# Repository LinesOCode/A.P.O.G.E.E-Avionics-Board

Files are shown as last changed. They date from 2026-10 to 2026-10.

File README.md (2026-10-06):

# **A.P.O.G.E.E Avionics**

## Introduction
Hi! Welcome to my project, A.P.O.G.E.E Avionics! I Made this project as a challenge to myself, mainly because I want to soon be able to make a rocket that is entirely my own, design, build, and electronics, and this is a HUGE leap out to that, with the electronics outta the way, I can learn many, many things to come!

A.P.O.G.E.E stands for Avionics, Power, Orientation, Guidance, and Electronics Engine, it represents all of the things I want this project to grow into, and I hope it really does!

## How it works - 
### *Hardware*

This project is mainly based around the Raspberry Pi 2350 Series, i have designed this chip to work with the 2350B/2354B, as they have built in QSPI memory, and without it, you cannot upload the code. For the components, I wont go into extreme depth, but here is the most important things and what they are used for - 

The ***MPU*** - Raspberry Pi 2354B (Main Processing Unit, The Brains of the Avionics Board)

The ***Accelerometer*** - LIS2DH12TR from STMicroelectronics (Sees how fast the rocket changes speed, and uses that to find the speed of the rocket)

The ***Barometer*** - SPL07-003 from Goertek (Finds the hight of the rocket somehow idk man electronics are weird)

The ***Gyroscope*** - A3G4250DTR from STMicroelectronics (Finds the orientation of the rocket, so that we know if we are aiming straight at the ground or up at the sky)

The ***Inertial Mesurement Unit*** - LSM6DS3TR-C from STMicroelectronics (Backup for the Accelerometer and Gyroscope, and also includes a temperature sensor, so I can collect data too!)

The ***Radio Transceiver*** - LoRa2 by Ai Thinker (Dont ask why the company has the word Ai in it, its one of the only ones that work, It is used to send the telemetry data back to my computer)

### *Software*

***Code*** - I coded this project in C++, mainly because of the speed and reliability it has when in a task such as this, and as a fair declaration, I did use AI to code this, as I have no idea on how to use or code those, and it would take a substantial amount of time to learn it, and I WILL add to the code in the future, at least until it is reliable, but as of this being written, I don't have the PCB, nor do i even have funding, so I cant even test the code.

***The Filter*** - For this, I am using an Extended Kalman Filter based code, mainly because of its perks in the aerospace field, and just how good it is a weighting the different data between the components.

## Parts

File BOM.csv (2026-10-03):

Index | LCSC# | MPN | Manufacturer | Package | Customer # | Description | RoHS | Quantity | MOQ | Multiple | Unit Price($) | Extended Price($) | Product Link
1 | C107077 | CC0603KRX7R9BB181 | YAGEO | 603 |  | 180pF ±10% 50V Ceramic Capacitor X7R 0603 | yes | 50 | 50 | 50 | 0.0128 | 0.64 | https://www.lcsc.com/product-detail/C107077.html
2 | C10811 | CNY17F-2 | LITEON | DIP-6 |  | 150mA 300mV@10mA,2.5mA 70V 6V 1.45V DC DIP-6 Transistor, Photovoltaic Output Optoisolators RoHS | yes | 5 | 1 | 1 | 0.0837 | 0.42 | https://www.lcsc.com/product-detail/C10811.html
3 | C51118 | AP2112K-3.3TRG1 | DIODES | SOT-25-5 |  | 3.3V Positive Fixed SOT-25-5 Voltage Regulators - Linear, Low Drop Out (LDO) Regulators RoHS | yes | 5 | 5 | 5 | 0 | 0 | https://www.lcsc.com/product-detail/C51118.html
4 | C15850 | CL21A106KAYNNNE | Samsung Electro-Mechanics | 805 |  | 10uF ±10% 25V Ceramic Capacitor X5R 0805 | yes | 20 | 20 | 20 | 0 | 0 | https://www.lcsc.com/product-detail/C15850.html
5 | C4944014 | 12M 16PF 50PPM | SOSET | HC-49S-SMD-2P-Mini |  | Crystal 12MHz ±50ppm 16pF HC-49S-SMD-2P-Mini | yes | 10 | 10 | 10 | 0.0382 | 0.38 | https://www.lcsc.com/product-detail/C4944014.html
6 | C561716 | FN03N270J500PLG | PSA | 201 |  | 27pF ±5% 50V Ceramic Capacitor C0G 0201 | yes | 100 | 100 | 100 | 0.0012 | 0.12 | https://www.lcsc.com/product-detail/C561716.html
7 | C21190 | 0603WAF1001T5E | UNI-ROYAL | 603 |  | 1kΩ ±1% 100mW 0603 Thick Film Resistor | yes | 100 | 100 | 100 | 0.0033 | 0.33 | https://www.lcsc.com/product-detail/C21190.html
8 | C14663 | CC0603KRX7R9BB104 | YAGEO | 603 |  | 100nF ±10% 50V Ceramic Capacitor X7R 0603 | yes | 50 | 50 | 50 | 0 | 0 | https://www.lcsc.com/product-detail/C14663.html
9 | C25804 | 0603WAF1002T5E | UNI-ROYAL | 603 |  | 10kΩ ±1% 100mW 0603 Thick Film Resistor | yes | 100 | 100 | 100 | 0.004 | 0.4 | https://www.lcsc.com/product-detail/C25804.html
10 | C90039 | Ra-02 | Ai-Thinker | SMD-16P |  | IPEX interface -141dBm SPI SMD-16P RF Transceiver Modules and Modems RoHS | yes | 5 | 1 | 1 | 7.4885 | 37.44 | https://www.lcsc.com/product-detail/C90039.html
11 | C5356059 | CON-SMA-EDGE-S | RF Solutions | SMD |  | SMD Coaxial Connector (RF) Assemblies RoHS | yes | 2 | 1 | 1 | 4.2063 | 8.41 | https://www.lcsc.com/product-detail/C5356059.html
12 | C20917 | AO3400A | AOS | SOT-23 |  | N-Channel 30V Surface Mount SOT-23-3L | yes | 25 | 5 | 5 | 0.0853 | 2.13 | https://www.lcsc.com/product-detail/C20917.html
13 | C2933369 | FRC0805F2200TS | FOJAN | 805 |  | 220Ω ±1% 125mW 0805 Thick Film Resistor | yes | 100 | 100 | 100 | 0.004 | 0.4 | https://www.lcsc.com/product-detail/C2933369.html
14 | C2909831 | 1N4007 | YONGYUTAI | SMA |  | Diode Independent 1kV 1A Surface Mount SMA | yes | 50 | 50 | 50 | 0.0087 | 0.44 | https://www.lcsc.com/product-detail/C2909831.html
15 | C3253727 | SPL07-003 | Goertek | SMD-10P |  | 30Kpa~1.1bar SMD-10P Pressure Sensors, Transducers RoHS | yes | 6 | 1 | 1 | 0.8817 | 5.29 | https://www.lcsc.com/product-detail/C3253727.html
16 | C967633 | LSM6DS3TR-C | ST | LGA-14(2.5x3) |  | LGA-14(2.5x3) IMUs (Inertial Measurement Units) RoHS | yes | 6 | 1 | 1 | 1.5274 | 9.16 | https://www.lcsc.com/product-detail/C967633.html
17 | C110926 | LIS2DH12TR | ST | LGA-12(2x2) |  | LGA-12(2x2) Accelerometers RoHS | yes | 6 | 1 | 1 | 0.9328 | 5.6 | https://www.lcsc.com/product-detail/C110926.html
18 | C2655092 | A3G4250DTR | ST | TFLGA-16 |  | TFLGA-16 Gyroscopes RoHS | yes | 6 | 1 | 1 | 1.8523 | 11.11 | https://www.lcsc.com/product-detail/C2655092.html
19 | C165948 | TYPE-C-31-M-12 | Korean Hroparts Elec | SMD |  | USB-C (USB TYPE-C) Receptacle Connector 16 Position Surface Mount | yes | 10 | 5 | 5 | 0.1724 | 1.72 | https://www.lcsc.com/product-detail/C165948.html
20 | C55098610 | HRC0805F5101FNTN | HWA CHN | 805 |  | 125mW 5.1kΩ 150V Thick Film Resistor ±1% ±100ppm/℃ 0805 Chip Resistor - Surface Mount | yes | 100 | 100 | 100 | 0.0012 | 0.12 | https://www.lcsc.com/product-detail/C55098610.html
21 | C318884 | TS-1187A-B-A-B | XKB Connection | SMD-4P,5.1x5.1mm |  | Tactile Switch SPST 160gf 1.5mm 5.1mm x 5.1mm Surface Mount | yes | 20 | 20 | 20 | 0.0207 | 0.41 | https://www.lcsc.com/product-detail/C318884.html
22 | C2286 | KT-0603R | Hubei KENTO Elec | 603 |  | Red 645nm LED Indication - Discrete 2.4V 0603 | yes | 100 | 100 | 100 | 0.0075 | 0.75 | https://www.lcsc.com/product-detail/C2286.html
23 | C2287 | KT-0603Y | Hubei KENTO Elec | 603 |  | Yellow 596nm LED Indication - Discrete 2.4V 0603 | yes | 50 | 50 | 50 | 0.0108 | 0.54 | https://www.lcsc.com/product-detail/C2287.html
24 | C2297 | KT-0805G | Hubei KENTO Elec | 805 |  | Emerald Green 525nm LED Indication - Discrete 2.6V~3.1V 0805 | yes | 50 | 50 | 50 | 0.0165 | 0.83 | https://www.lcsc.com/product-detail/C2297.html
25 | C2933198 | FRC0603F3300TS | FOJAN | 603 |  | 330Ω ±1% 100mW 0603 Thick Film Resistor | yes | 100 | 100 | 100 | 0.0027 | 0.27 | https://www.lcsc.com/product-detail/C2933198.html
26 | C55014110 | SMD-0955-05-27 | S&S | SMD,9x9mm |  | Active Buzzer (Built-in Driving Circuit) 2.7kHz 5V Electromagnetic SMD,9x9mm Alarms, Buzzers, and Sirens RoHS | yes | 6 | 1 | 1 | 0.1983 | 1.19 | https://www.lcsc.com/product-detail/C55014110.html
27 | C39843328 | RP2354B | Raspberry Pi | QFN-80-EP(10x10) |  | ARM Cortex-M33 32 Bit 150MHz QFN-80-EP(10x10) Microcontrollers | yes | 6 | 1 | 1 | 1.5799 | 9.48 | https://www.lcsc.com/product-detail/C39843328.html
28 | C41367225 | BSMD1206C-1300T | BHFUSE | 1206 |  | 3A 72V Fuse Surface Mount 1206 | yes | 30 | 10 | 10 | 0.0575 | 1.73 | https://www.lcsc.com/product-detail/C41367225.html
29 | C176959 | AP2210K-3.3TRG1 | DIODES | SOT-23-5 |  | 3.3V Positive Fixed SOT-23-5 Voltage Regulators - Linear, Low Drop Out (LDO) Regulators RoHS | yes | 5 | 5 | 5 | 0.1912 | 0.96 | https://www.lcsc.com/product-detail/C176959.html
30 | C2907002 | FRC0603F1001TS | FOJAN | 603 |  | 1kΩ ±1% 100mW 0603 Thick Film Resistor | yes | 100 | 100 | 100 | 0.0028 | 0.28 | https://www.lcsc.com/product-detail/C2907002.html
31 | C23848 | MBR0520LT1G | onsemi | SOD-123 |  | Diode 20V 500mA Surface Mount SOD-123 | yes | 50 | 5 | 5 | 0.084 | 4.2 | https://www.lcsc.com/product-detail/C23848.html
32 | C29266 | CL05A105KO5NNNC | Samsung Electro-Mechanics | 402 |  | 1uF ±10% 16V Ceramic Capacitor X5R 0402 | yes | 50 | 50 | 50 | 0.0082 | 0.41 | https://www.lcsc.com/product-detail/C29266.html
33 | C49441431 | JBL-102010052 | JBL | SMD |  | -40℃~+85℃ Push-Push 1.8mm Connector and Ejector MicroSD Card (TF Card) SMD PC Card Sockets RoHS | yes | 5 | 5 | 5 | 0.0874 | 0.44 | https://www.lcsc.com/product-detail/C49441431.html
34 | C500019 | DB127V-5.0-2P-BU-S | DORABO | Through Hole,P=5mm |  | 2 Position Wire to Board Terminal Block Through Hole 5mm | yes | 50 | 5 | 5 | 0.1264 | 6.32 | https://www.lcsc.com/product-detail/C500019.html
Total Components Cost - $127 | Tax and Shipping included in price shown
PCB Cost - $160 | Tax and Shipping included in price shown
Manufaturing Tools Cost - $123 | Tax and Shipping included in price shown
 | Soldering Iron and Heat Gun Station - $60
 | Solder Paste - $15
 | Flux - $15
 | Helping Hands - $25
Total Cost - $410

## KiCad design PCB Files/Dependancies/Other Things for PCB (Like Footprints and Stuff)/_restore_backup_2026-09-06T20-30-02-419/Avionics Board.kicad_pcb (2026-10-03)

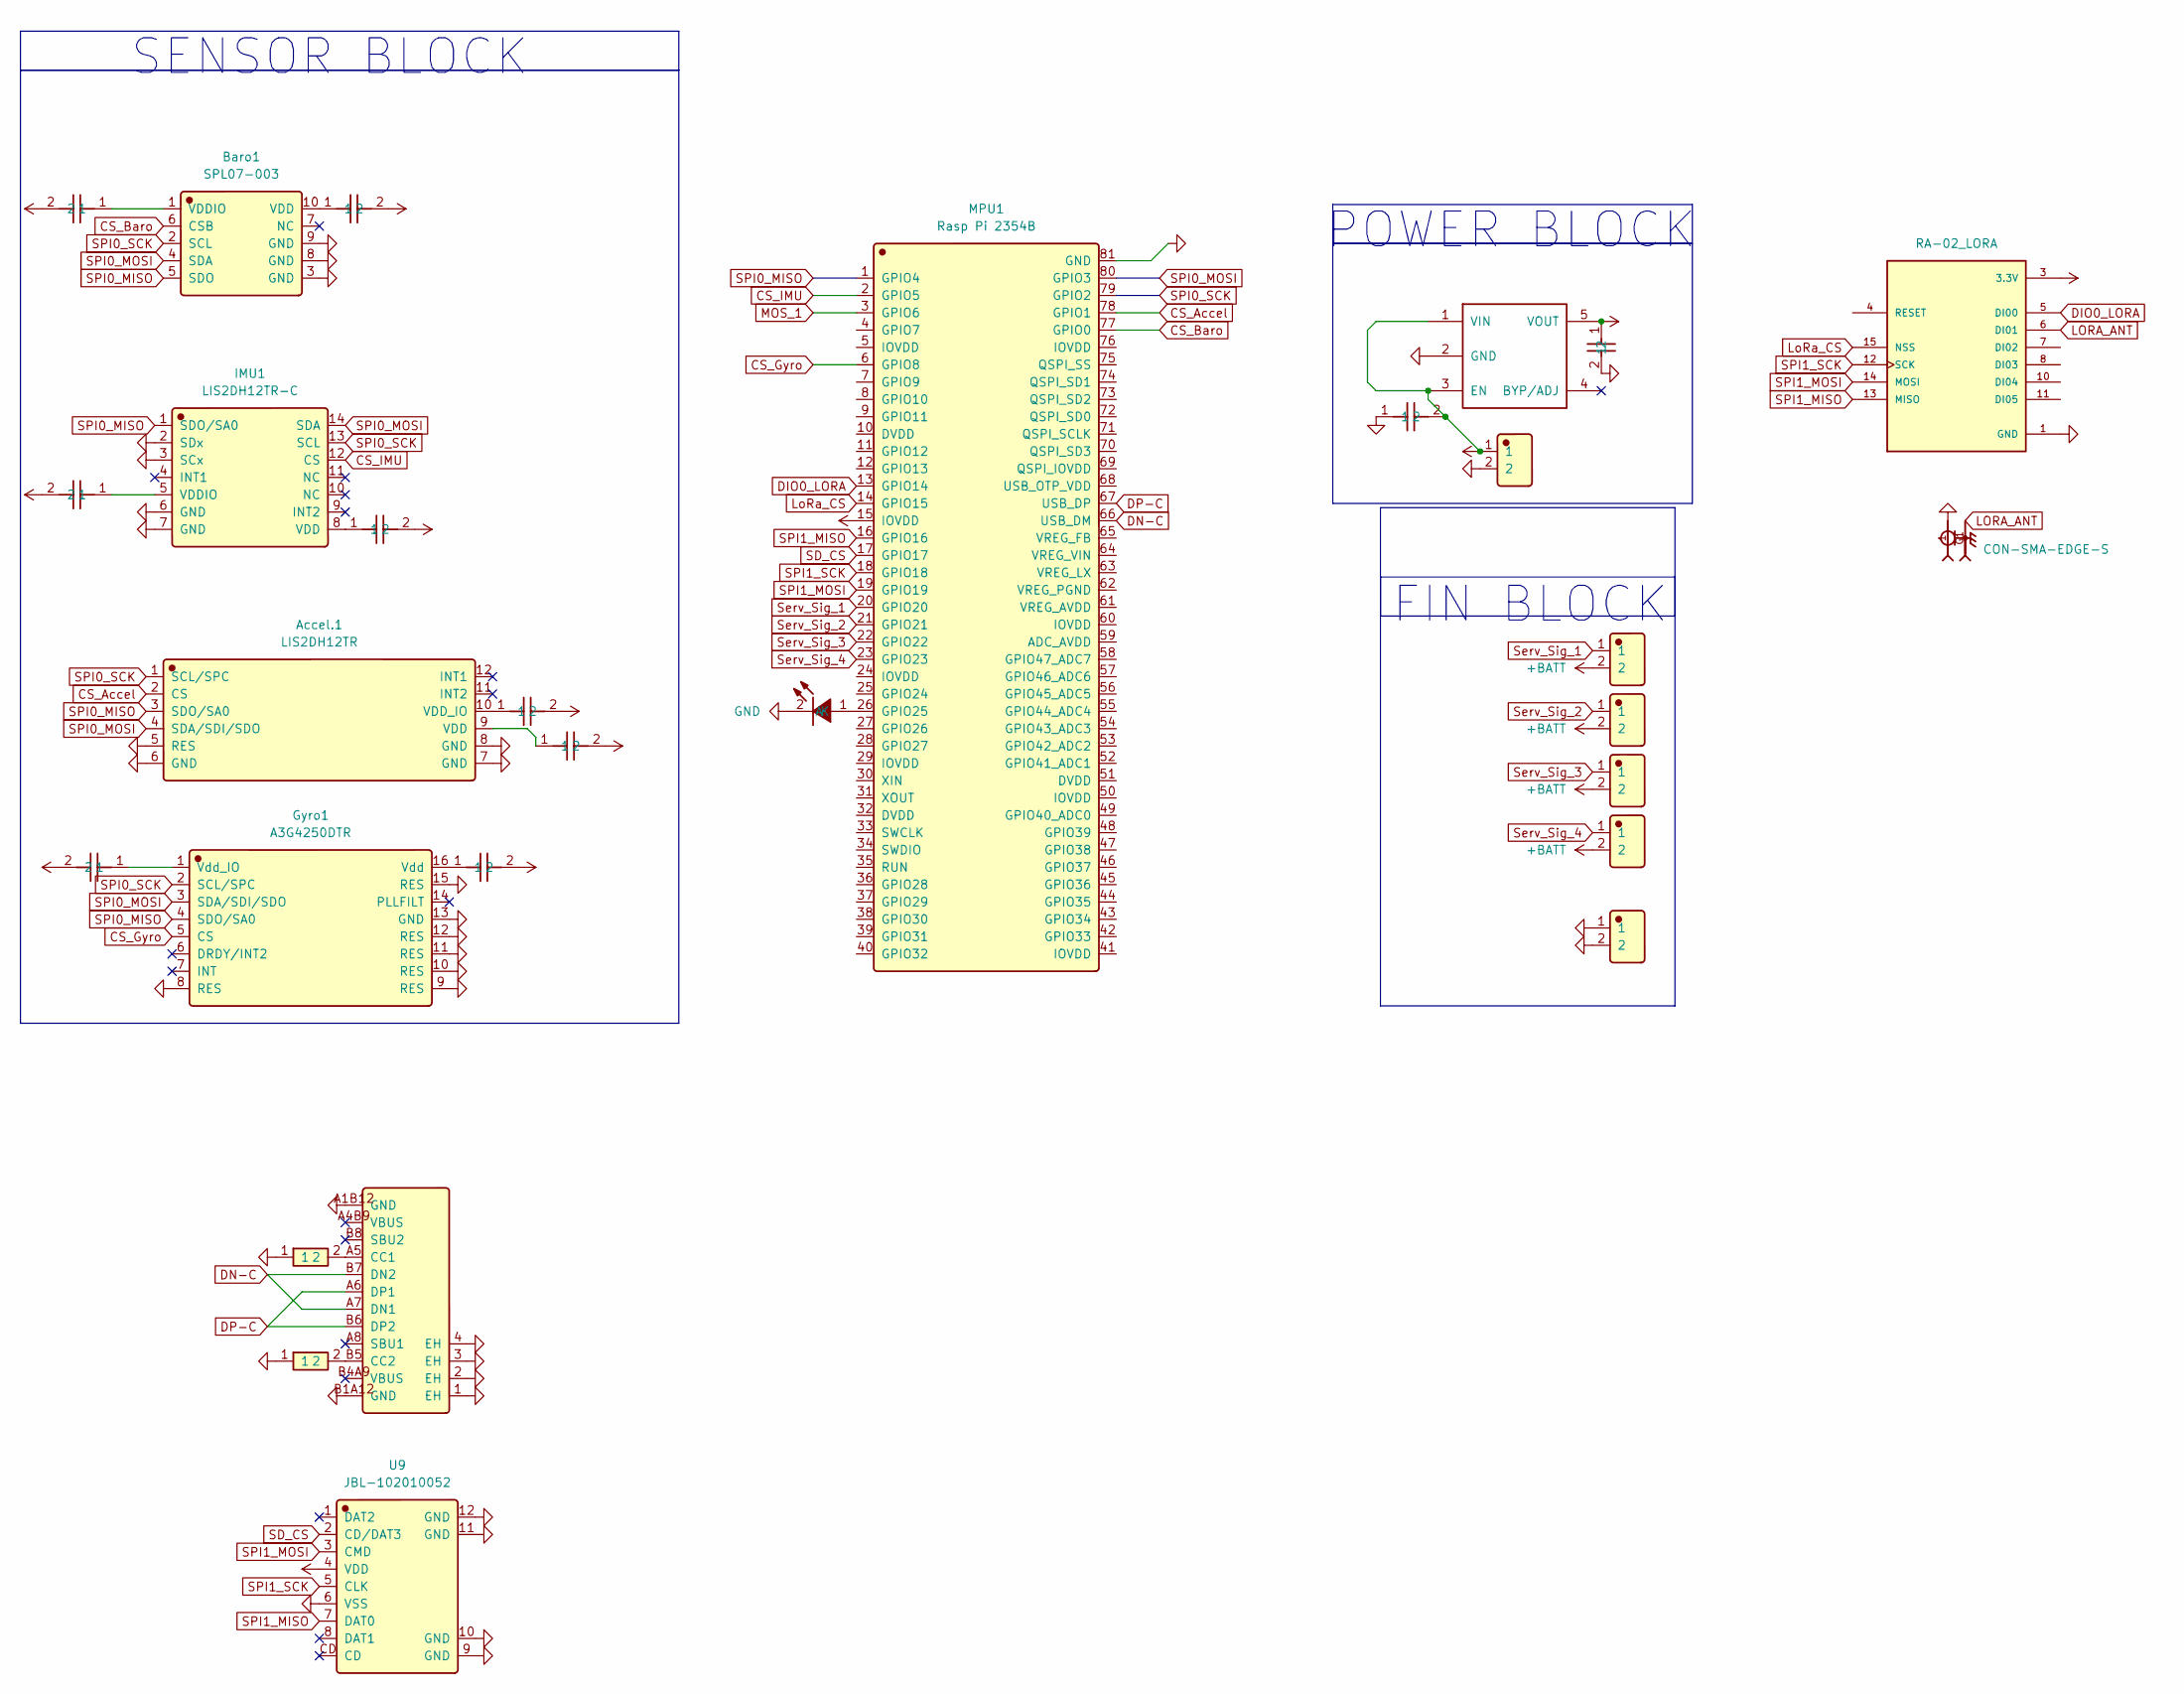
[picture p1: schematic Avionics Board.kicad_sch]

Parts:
Accel.1: LIS2DH12TR; LGA-12_2x2mm_P0.5mm; Manufacturer Part LIS2DH12TR; LCSC C110926
Baro1: SPL07-003; Manufacturer Part SPL07-003; LCSC C3253727
C1, C2, C3, C4, C5, C6, C7, C8: .1 uF; C_0603_1608Metric; Manufacturer Part CC0603KRX7R9BB104; LCSC C14663
C9: CL21A106KAYNNNE; C_0805_2012Metric; Manufacturer Part CL21A106KAYNNNE; LCSC C15850
C10: CL05A105KO5NNNC; C_0402_1005Metric; Manufacturer Part CL05A105KO5NNNC; LCSC C29266
Gyro1: A3G4250DTR; QFN-16-1EP_4x4mm_P0.65mm_EP2.1x2.1mm; Manufacturer Part A3G4250DTR; LCSC C2655092
IMU1: LIS2DH12TR-C; Bosch_LGA-14_3x2.5mm_P0.5mm; Manufacturer Part LSM6DS3TR-C; LCSC C967633
J1: CON-SMA-EDGE-S; RFSOLUTIONS_CON-SMA-EDGE-S; PARTREV 1
LED1: 0805G_Green; Manufacturer Part KT-0805G; LCSC C2297
MPU1: Rasp Pi 2354B; QFN-80-1EP_10x10mm_P0.4mm_EP3.4x3.4mm; Manufacturer Part RP2354B; LCSC C39843328
R1, R2: HRC0805F5101FNTN; R_0805_2012Metric; Manufacturer Part HRC0805F5101FNTN; LCSC C55098610
U2: Volt_Reg; SOT-23-5; Manufacturer Part AP2210K-3.3TRG1; LCSC C176959
U3, U4, U5, U6, U7, U11: DB127V-5_0-2P-BU-S; Manufacturer Part DB127V-5.0-2P-BU-S; LCSC C500019
U9: JBL-102010052; Micro_SD_-_Avionics; Manufacturer Part JBL-102010052; LCSC C49441431
U10: RA-02_LORA; MODULE_RA-02_LORA; PARTREV 2018/03/02
USBC1: TYPE-C-31-M-12; USB_C_Receptacle_HRO_TYPE-C-31-M-12; Manufacturer Part TYPE-C-31-M-12; LCSC C165948

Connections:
+3.3V: C1.2, C2.2, C3.2, C4.2, C5.2, C6.2, C7.2, C8.2, C10.1, MPU1.15 (IOVDD), U2.5 (VOUT), U9.4 (VDD), U10.3 (3.3V)
+BATT: C9.2, U2.1 (VIN), U2.3 (EN), U3.2, U4.2, U5.2, U6.2, U11.1
CS_Accel: Accel.1.2 (CS), MPU1.78 (GPIO1)
CS_Baro: Baro1.6 (CSB), MPU1.77 (GPIO0)
CS_Gyro: Gyro1.5 (CS), MPU1.6 (GPIO8)
CS_IMU: IMU1.12 (CS), MPU1.2 (GPIO5)
DIO0_LORA: MPU1.13 (GPIO14), U10.5 (DI00)
DN-C: MPU1.66 (USB_DM), USBC1.A7 (DN1), USBC1.B7 (DN2)
DP-C: MPU1.67 (USB_DP), USBC1.A6 (DP1), USBC1.B6 (DP2)
GND: Accel.1.5 (RES), Accel.1.6 (GND), Accel.1.7 (GND), Accel.1.8 (GND), Baro1.3 (GND), Baro1.8 (GND), Baro1.9 (GND), C9.1, C10.2, Gyro1.8 (RES), Gyro1.9 (RES), Gyro1.10 (RES), Gyro1.11 (RES), Gyro1.12 (RES), Gyro1.13 (GND), Gyro1.15 (RES), IMU1.2 (SDx), IMU1.3 (SCx), IMU1.6 (GND), IMU1.7 (GND), J1.1, LED1.2 (K), MPU1.81 (GND), R1.1, R2.1, U2.2 (GND), U7.1, U7.2, U9.6 (VSS), U9.9 (GND), U9.10 (GND), U9.11 (GND), U9.12 (GND), U10.1 (GND), U10.2 (GND), U10.9 (GND), U10.16 (GND), U11.2, USBC1.1 (EH), USBC1.2 (EH), USBC1.3 (EH), USBC1.4 (EH), USBC1.A1B12 (GND), USBC1.B1A12 (GND)
LoRa_CS: MPU1.14 (GPIO15), U10.15 (NSS)
MOS_1: MPU1.3 (GPIO6)
unnamed: Accel.1.9 (VDD), C1.1
unnamed: Accel.1.10 (VDD_IO), C2.1
unnamed: Baro1.10 (VDD), C7.1
unnamed: Baro1.1 (VDDIO), C8.1
unnamed: C5.1, Gyro1.16 (Vdd)
unnamed: C6.1, Gyro1.1 (Vdd_IO)
unnamed: C3.1, IMU1.8 (VDD)
unnamed: C4.1, IMU1.5 (VDDIO)
unnamed: J1.G1, J1.G2, J1.G3, J1.G4, U10.6 (DI01)
unnamed: LED1.1 (A), MPU1.26 (GPIO25)
unnamed: R2.2, USBC1.A5 (CC1)
unnamed: R1.2, USBC1.B5 (CC2)
SD_CS: MPU1.17 (GPIO17), U9.2 (CD/DAT3)
SPI0_MISO: Accel.1.3 (SDO/SA0), Baro1.5 (SDO), Gyro1.4 (SDO/SA0), IMU1.1 (SDO/SA0), MPU1.1 (GPIO4)
SPI0_MOSI: Accel.1.4 (SDA/SDI/SDO), Baro1.4 (SDA), Gyro1.3 (SDA/SDI/SDO), IMU1.14 (SDA), MPU1.80 (GPIO3)
SPI0_SCK: Accel.1.1 (SCL/SPC), Baro1.2 (SCL), Gyro1.2 (SCL/SPC), IMU1.13 (SCL), MPU1.79 (GPIO2)
SPI1_MISO: MPU1.16 (GPIO16), U9.7 (DAT0), U10.13 (MISO)
SPI1_MOSI: MPU1.19 (GPIO19), U9.3 (CMD), U10.14 (MOSI)
SPI1_SCK: MPU1.18 (GPIO18), U9.5 (CLK), U10.12 (SCK)
Serv_Sig_1: MPU1.20 (GPIO20), U3.1
Serv_Sig_2: MPU1.21 (GPIO21), U4.1
Serv_Sig_3: MPU1.22 (GPIO22), U5.1
Serv_Sig_4: MPU1.23 (GPIO23), U6.1

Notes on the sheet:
FIN BLOCK
POWER BLOCK
SENSOR BLOCK

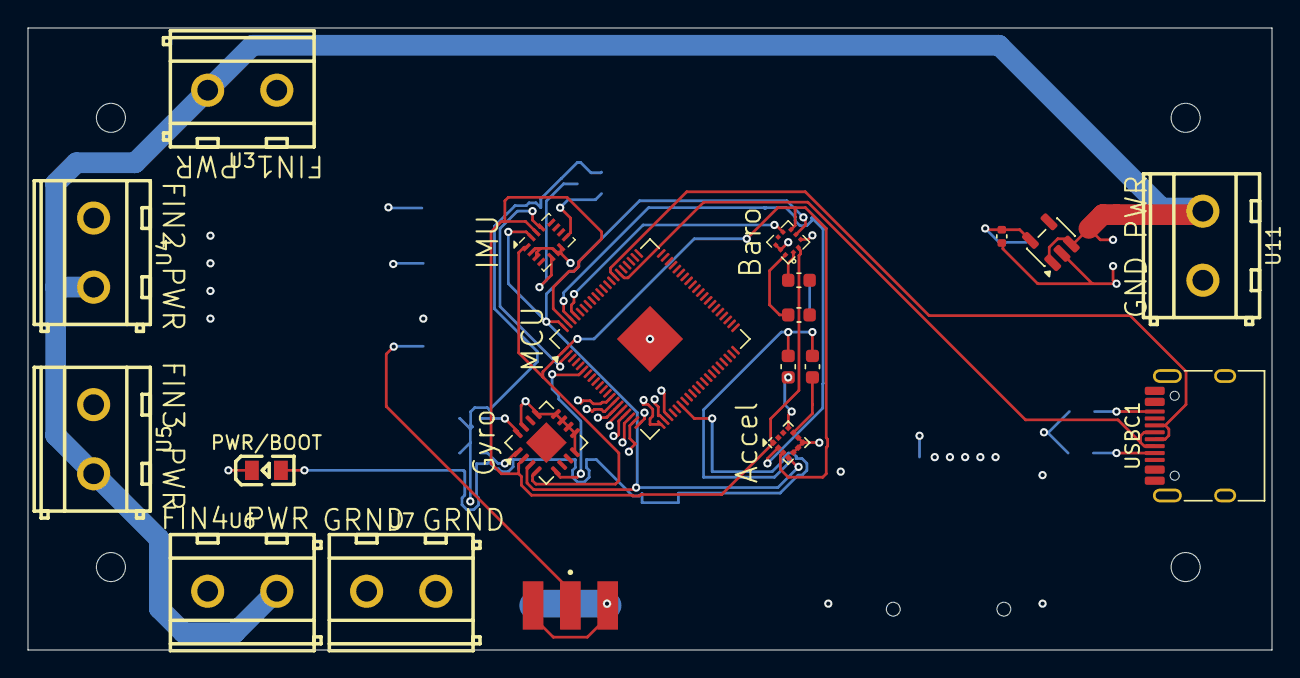
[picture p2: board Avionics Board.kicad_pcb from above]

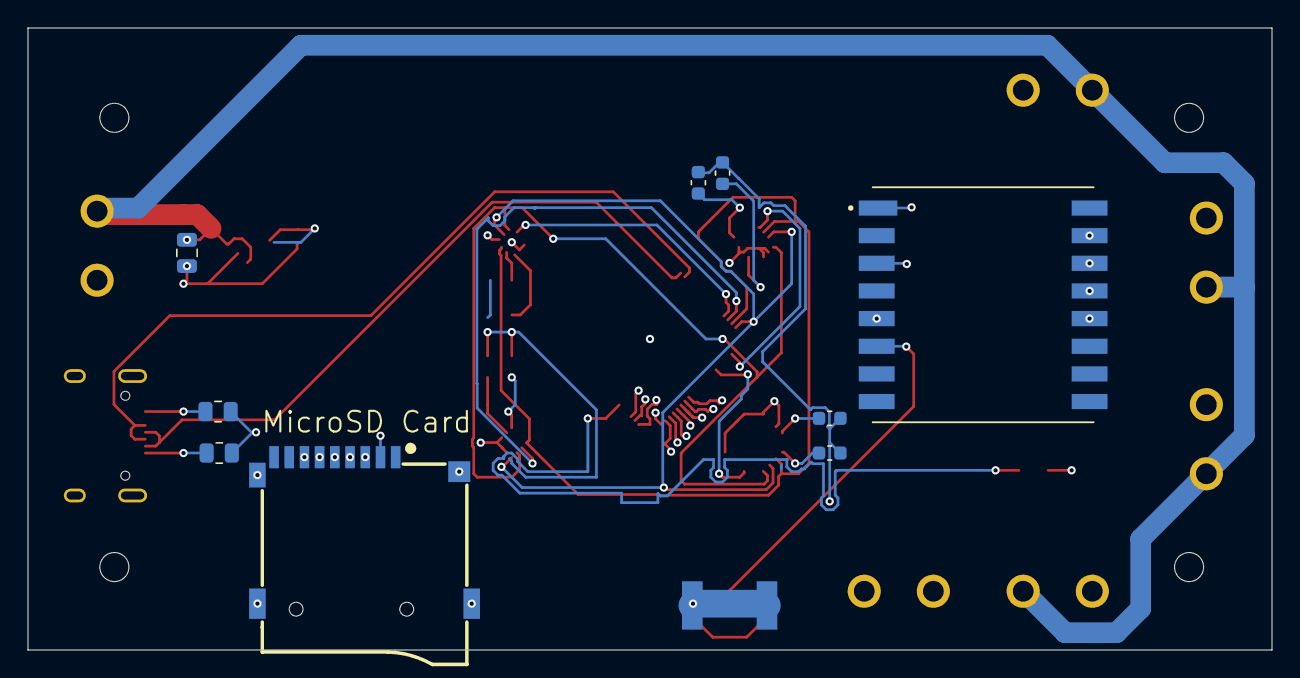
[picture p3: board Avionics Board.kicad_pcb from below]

Board: 4 copper layers, 90.0 x 45.0 mm, 27 parts (8 on the bottom side), 31 nets.

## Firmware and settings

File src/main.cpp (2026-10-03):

#include <Arduino.h>
#include <SPI.h>
#include <Servo.h>
#include <RadioLib.h>
#include <SD.h>
#include <math.h>
#include <string.h>
#include <stdio.h>

<<<<<<< HEAD

// ========================== Deadlock Safety ================================

spin_lock_t *telemetryLock;   // Remains purely for the Core0 -> Core1 FIFO snapshot packet
spin_lock_t *sensorBusLock;   // ONLY if multiple tasks on Core 0 need to share sensorSPI
spin_lock_t *storageBusLock;  // ONLY if multiple tasks on Core 1 need to share the standard SPI


=======
// Minimal watchdog stubs for single-core ARM builds (no Pico watchdog)
static inline void watchdog_update() {}
static inline void watchdog_enable(uint32_t ms, bool pause_on_debug) {}
>>>>>>> e234959169edb00d9b9b414ebf627fc5142cae8a

// ========================== PIN ASSIGNMENTS ================================
// All four sensors share this SPI bus. Only one CS line may be low at a time.
// Keep board wiring changes in this block.
// Sensor bus: configurable SPI pins (change these variables if you re-wire)
// Default mapping provided by user (GPIO numbers):
// SCK = GPIO2, MOSI = GPIO3, MISO = GPIO4
const uint8_t SENSOR_SPI_SCK_PIN = 2;
const uint8_t SENSOR_SPI_MOSI_PIN = 3;
const uint8_t SENSOR_SPI_MISO_PIN = 4;
// Storage/radio bus: Arduino global SPI0 pins, separate from all sensors.
const uint8_t STORAGE_SPI_SCK_PIN = 18;
const uint8_t STORAGE_SPI_MOSI_PIN = 19;
const uint8_t STORAGE_SPI_MISO_PIN = 16;
// Sensor chip-selects (changeable variables)
// Provided mapping from user:
// IMU CS GPIO5, Gyro CS GPIO8, Baro CS GPIO0, Accel CS GPIO1
const uint8_t IMU_SENSOR_CS = 5;   // ST LSM6DS3TR accelerometer + gyro
const uint8_t GYRO_SENSOR_CS = 8;  // ST A3G4250DTR gyro
const uint8_t BARO_SENSOR_CS = 0;  // Goertek SPL07-003 barometer
const uint8_t ACCEL_SENSOR_CS = 1; // ST LIS2DH12TR accelerometer
const uint8_t MOSFET_ARM_INPUT_PIN = 12;
const uint8_t DROGUE_PARACHUTE_GATE_PIN = 26;
const uint8_t MAIN_PARACHUTE_GATE_PIN = 9;
const uint8_t FIN_1_POWER_GATE_PIN = 13;
const uint8_t FIN_2_POWER_GATE_PIN = 14;
const uint8_t FIN_3_POWER_GATE_PIN = 15;
const uint8_t FIN_4_POWER_GATE_PIN = 20;
const uint8_t FIN_1_SERVO_SIGNAL_PIN = 21;
const uint8_t FIN_2_SERVO_SIGNAL_PIN = 22;
const uint8_t FIN_3_SERVO_SIGNAL_PIN = 23;
const uint8_t FIN_4_SERVO_SIGNAL_PIN = 24;
const uint8_t MISC_MOSFET_GATE_PIN = 25;
const uint8_t SD_CARD_CS_PIN = 27;       // MicroSD card chip select, storage SPI0
const uint8_t LORA_RADIO_CS_PIN = 28;    // HopeRF RFM95W-915S2 NSS, storage SPI0
const uint8_t LORA_RADIO_RESET_PIN = 1;
const uint8_t LORA_RADIO_DIO0_PIN = 0;
const uint8_t W25Q16_FLASH_CS_PIN = 3;   // Winbond W25Q16JVSSIQ, 16 Mbit
const float high_altitude_threshold_m = 1000.0f;
const float high_altitude_reset_m = 950.0f;
const uint8_t high_altitude_confirmations = 8;
const uint32_t sensor_health_period_ms = 250;
const uint8_t sensor_recovery_limit = 3;
const float max_fin_correction_deg = 12.0f;
const float maximum_control_angle_deg = 45.0f;
const bool FIN_CONTROL_ENABLED = false; // Explicitly enable only after restrained bench testing.
const float ATTITUDE_ACCEL_CORRECTION = 0.02f;
const uint32_t BAROMETER_SAMPLE_PERIOD_MS = 62;
const uint32_t TELEMETRY_PERIOD_MS = 50;
const uint32_t SD_FLUSH_PERIOD_MS = 1000;
const uint8_t INTER_RP_PACKET_MAGIC = 0xa7;

// Use a dedicated SPI instance for sensors so pins can be remapped at runtime
SPIClass sensorSPI;
SPISettings sensor_spi(8000000, MSBFIRST, SPI_MODE0);
SPISettings storage_spi(25000000, MSBFIRST, SPI_MODE0);
File flightLog;
SX1276 loraRadio = new Module(LORA_RADIO_CS_PIN, LORA_RADIO_DIO0_PIN, LORA_RADIO_RESET_PIN,
                              RADIOLIB_NC, SPI, SPISettings(8000000, MSBFIRST, SPI_MODE0));
bool sdCardReady = false;
bool loraReady = false;
bool flashReady = false;
uint32_t flashJedecId = 0;
uint32_t lastSdFlushMs = 0;
uint16_t interRpSequence = 0;
// single-core build: no spinlocks or multicore usage

struct FlightStatePacket {
  uint8_t magic;
  uint8_t version;
  uint16_t sequence;
  uint32_t timestampMs;
  float altitudeM;
  float velocityMps;
  float rollRad;
  float pitchRad;
  float pressurePa;
  uint8_t sensorHealthMask;
  uint8_t checksum;
};

static void publishRemoteTelemetry(const FlightStatePacket &packet);

static uint8_t packetChecksum(const FlightStatePacket &packet) {
  const uint8_t *bytes = reinterpret_cast<const uint8_t *>(&packet);
  uint8_t checksum = 0;
  for (size_t index = 0; index < sizeof(packet) - 1; ++index) checksum ^= bytes[index];
  return checksum;
}

static uint32_t readW25q16JedecId() {
  uint8_t id[3];
  SPI.beginTransaction(storage_spi);
  digitalWrite(W25Q16_FLASH_CS_PIN, LOW);
  SPI.transfer(0x9f);
  id[0] = SPI.transfer(0);
  id[1] = SPI.transfer(0);
  id[2] = SPI.transfer(0);
  digitalWrite(W25Q16_FLASH_CS_PIN, HIGH);
  SPI.endTransaction();
  return (static_cast<uint32_t>(id[0]) << 16) |
         (static_cast<uint32_t>(id[1]) << 8) | id[2];
}

static void initializeExternalMemory() {
  pinMode(W25Q16_FLASH_CS_PIN, OUTPUT);
  digitalWrite(W25Q16_FLASH_CS_PIN, HIGH);
  flashJedecId = readW25q16JedecId();
  flashReady = flashJedecId == 0xef4015UL;
  if (flashReady) {
    Serial.println("W25Q16 detected on core 0: external 16 Mbit SPI/QSPI flash");
  } else {
    Serial.println("W25Q16 not detected; onboard flash is unchanged");
  }
}

static uint8_t spiRead8(uint8_t chipSelect, uint8_t reg) {
  sensorSPI.beginTransaction(sensor_spi);
  digitalWrite(chipSelect, LOW);
  sensorSPI.transfer(reg | 0x80);
  uint8_t value = sensorSPI.transfer(0);
  digitalWrite(chipSelect, HIGH);
  sensorSPI.endTransaction();
  return value;
}

static void spiWrite8(uint8_t chipSelect, uint8_t reg, uint8_t value) {
  sensorSPI.beginTransaction(sensor_spi);
  digitalWrite(chipSelect, LOW);
  sensorSPI.transfer(reg & 0x7f);
  sensorSPI.transfer(value);
  digitalWrite(chipSelect, HIGH);
  sensorSPI.endTransaction();
}

static void spiRead(uint8_t chipSelect, uint8_t reg, uint8_t *buffer, size_t length) {
  sensorSPI.beginTransaction(sensor_spi);
  digitalWrite(chipSelect, LOW);
  sensorSPI.transfer(reg | 0x80 | (length > 1 ? 0x40 : 0));
  memset(buffer, 0, length);
  sensorSPI.transfer(buffer, length);
  digitalWrite(chipSelect, HIGH);
  sensorSPI.endTransaction();
}

enum SensorId : uint8_t { SENSOR_SPL07, SENSOR_LSM6, SENSOR_LIS2DH, SENSOR_A3G4250 };
uint8_t sensorFailures[4] = {0, 0, 0, 0};
bool sensorHealthy[4] = {false, false, false, false};
uint32_t lastSensorHealthCheck = 0;

class Spl07 {
 public:
  explicit Spl07(uint8_t chipSelect) : chipSelect_(chipSelect) {}

  bool begin() {
    if (spiRead8(chipSelect_, 0x0d) != 0x10) return false;
    uint8_t calibration[18];
    spiRead(chipSelect_, 0x10, calibration, sizeof(calibration));
    c0_ = signExtend((calibration[0] << 4) | (calibration[1] >> 4), 12);
    c1_ = signExtend(((calibration[1] & 0x0f) << 8) | calibration[2], 12);
    c00_ = signExtend((calibration[3] << 12) | (calibration[4] << 4) | (calibration[5] >> 4), 20);
    c10_ = signExtend(((calibration[5] & 0x0f) << 16) | (calibration[6] << 8) | calibration[7], 20);
    c01_ = signExtend((calibration[8] << 8) | calibration[9], 16);
    c11_ = signExtend((calibration[10] << 8) | calibration[11], 16);
    c20_ = signExtend((calibration[12] << 8) | calibration[13], 16);
    c21_ = signExtend((calibration[14] << 8) | calibration[15], 16);
    c30_ = signExtend((calibration[16] << 8) | calibration[17], 16);
    // 16 measurements/s, 8x oversampling for both pressure and temperature.
    spiWrite8(chipSelect_, 0x06, 0x24);
    spiWrite8(chipSelect_, 0x07, 0xa7);
    spiWrite8(chipSelect_, 0x08, 0x07);
    spiWrite8(chipSelect_, 0x09, 0x00);
    return true;
  }

  float pressurePa() {
    uint8_t data[6];
    spiRead(chipSelect_, 0x00, data, sizeof(data));
    int32_t pressure = signExtend((data[0] << 16) | (data[1] << 8) | data[2], 24);
    int32_t temperature = signExtend((data[3] << 16) | (data[4] << 8) | data[5], 24);
    float pressureScale = 7864320.0f; // 8x oversampling scale factor
    float temperatureScale = 7864320.0f;
    float pressureScaled = pressure / pressureScale;
    float temperatureScaled = temperature / temperatureScale;
    float pressureCompensated = c00_ + pressureScaled * (c10_ + pressureScaled * (c20_ + pressureScaled * c30_));
    pressureCompensated += temperatureScaled * c01_ + pressureScaled * temperatureScaled * (c11_ + pressureScaled * c21_);
    return pressureCompensated * 100.0f;
  }

 private:
  static int32_t signExtend(uint32_t value, uint8_t bits) {
    uint32_t sign = 1UL << (bits - 1);
    return (value ^ sign) - sign;
  }
  uint8_t chipSelect_;
  int32_t c0_ = 0, c1_ = 0, c00_ = 0, c10_ = 0;
  int32_t c01_ = 0, c11_ = 0, c20_ = 0, c21_ = 0, c30_ = 0;
};

struct Vector3 { float x; float y; float z; };
struct ImuSample { Vector3 acceleration; Vector3 gyro; };

static ImuSample readLsm6(uint8_t chipSelect) {
  uint8_t data[12];
  spiRead(chipSelect, 0x22, data, sizeof(data));
  const float gyroScale = 8.75e-3f * DEG_TO_RAD;
  const float accelScale = 0.061f * 9.80665e-3f;
  ImuSample sample;
  sample.acceleration = {((int16_t)(data[6] | data[7] << 8)) * accelScale,
                         ((int16_t)(data[8] | data[9] << 8)) * accelScale,
                         ((int16_t)(data[10] | data[11] << 8)) * accelScale};
  sample.gyro = {((int16_t)(data[0] | data[1] << 8)) * gyroScale,
                 ((int16_t)(data[2] | data[3] << 8)) * gyroScale,
                 ((int16_t)(data[4] | data[5] << 8)) * gyroScale};
  return sample;
}

static Vector3 readLis2dh(uint8_t chipSelect) {
  uint8_t data[6];
  spiRead(chipSelect, 0x28, data, sizeof(data));
  const float scale = 0.001f * 9.80665f; // +/-2 g, high-resolution mode
  return {((int16_t)(data[0] | data[1] << 8) >> 4) * scale,
          ((int16_t)(data[2] | data[3] << 8) >> 4) * scale,
          ((int16_t)(data[4] | data[5] << 8) >> 4) * scale};
}

static Vector3 readA3g4250(uint8_t chipSelect) {
  uint8_t data[6];
  spiRead(chipSelect, 0x28, data, sizeof(data));
  const float scale = 8.75e-3f * DEG_TO_RAD;
  return {((int16_t)(data[0] | data[1] << 8)) * scale,
          ((int16_t)(data[2] | data[3] << 8)) * scale,
          ((int16_t)(data[4] | data[5] << 8)) * scale};
}

class AltitudeKalman {
 public:
  void reset(float altitude) {
    altitude_ = altitude;
    velocity_ = 0.0f;
    p00_ = 1.0f;
    p01_ = 0.0f;
    p11_ = 1.0f;
  }
  void predict(float acceleration, float dt) {
    if (!isfinite(acceleration) || !isfinite(dt) || dt <= 0.0f || dt > 0.1f) return;
    altitude_ += velocity_ * dt + 0.5f * acceleration * dt * dt;
    velocity_ += acceleration * dt;
    float p00 = p00_ + dt * (2.0f * p01_ + dt * p11_) + processAcceleration_ * dt * dt * dt * dt / 4.0f;
    float p01 = p01_ + dt * p11_ + processAcceleration_ * dt * dt * dt / 2.0f;
    float p11 = p11_ + processAcceleration_ * dt * dt;
    p00_ = p00;
    p01_ = p01;
    p11_ = p11;
    if (!isfinite(altitude_) || !isfinite(velocity_) || !isfinite(p00_) ||
        !isfinite(p01_) || !isfinite(p11_) || p00_ < 0.0f || p11_ < 0.0f) {
      reset(0.0f);
    }
  }
  void correct(float measuredAltitude) {
    if (!isfinite(measuredAltitude) || !isfinite(altitude_) || !isfinite(p00_) ||
        !isfinite(p01_) || !isfinite(p11_)) return;
    float innovation = measuredAltitude - altitude_;
    float covariance01 = p01_;
    float innovationVariance = p00_ + measurementVariance_;
    if (innovationVariance <= 0.0f || !isfinite(innovationVariance)) return;
    float gainAltitude = p00_ / innovationVariance;
    float gainVelocity = p01_ / innovationVariance;
    altitude_ += gainAltitude * innovation;
    velocity_ += gainVelocity * innovation;
    p00_ = (1.0f - gainAltitude) * p00_;
    p01_ = (1.0f - gainAltitude) * covariance01;
    p11_ = p11_ - gainVelocity * covariance01;
    if (!isfinite(altitude_) || !isfinite(velocity_) || p00_ < 0.0f || p11_ < 0.0f) reset(0.0f);
  }
  void update(float acceleration, float measuredAltitude, float dt) {
    predict(acceleration, dt);
    correct(measuredAltitude);
  }
  float altitude() const { return altitude_; }
  float velocity() const { return velocity_; }

 private:
  float altitude_ = 0.0f, velocity_ = 0.0f;
  float p00_ = 1.0f, p01_ = 0.0f, p11_ = 1.0f;
  const float processAcceleration_ = 0.8f;
  const float measurementVariance_ = 2.5f;
};


class FinController {
 public:
  FinController() {}

  void begin() {
    fin1Servo.attach(FIN_1_SERVO_SIGNAL_PIN);
    fin2Servo.attach(FIN_2_SERVO_SIGNAL_PIN);
    fin3Servo.attach(FIN_3_SERVO_SIGNAL_PIN);
    fin4Servo.attach(FIN_4_SERVO_SIGNAL_PIN);
    setNeutral();
  }

  void disable() {
    setPower(false);
    setNeutral();
  }

  void correct(float roll, float pitch, bool armed) {
    if (!FIN_CONTROL_ENABLED || !armed || !isfinite(roll) || !isfinite(pitch) ||
        fabsf(roll) > maximum_control_angle_deg * DEG_TO_RAD ||
        fabsf(pitch) > maximum_control_angle_deg * DEG_TO_RAD) {
      disable();
      return;
    }
    setPower(true);
    float rollCorrection = constrain(-roll * RAD_TO_DEG, -max_fin_correction_deg, max_fin_correction_deg);
    float pitchCorrection = constrain(-pitch * RAD_TO_DEG, -max_fin_correction_deg, max_fin_correction_deg);
    writeAngle(0, pitchCorrection + rollCorrection);
    writeAngle(1, pitchCorrection - rollCorrection);
    writeAngle(2, -pitchCorrection - rollCorrection);
    writeAngle(3, -pitchCorrection + rollCorrection);
  }

 private:
  void setPower(bool enabled) {
    digitalWrite(FIN_1_POWER_GATE_PIN, enabled ? HIGH : LOW);
    digitalWrite(FIN_2_POWER_GATE_PIN, enabled ? HIGH : LOW);
    digitalWrite(FIN_3_POWER_GATE_PIN, enabled ? HIGH : LOW);
    digitalWrite(FIN_4_POWER_GATE_PIN, enabled ? HIGH : LOW);
  }

  void setNeutral() {
    fin1Servo.writeMicroseconds(1500);
    fin2Servo.writeMicroseconds(1500);
    fin3Servo.writeMicroseconds(1500);
    fin4Servo.writeMicroseconds(1500);
  }

  void writeAngle(uint8_t index, float correction) {
    correction = constrain(correction, -max_fin_correction_deg, max_fin_correction_deg);
    int pulse = static_cast<int>(1500.0f + correction * (400.0f / 90.0f));
    switch (index) {
      case 0: fin1Servo.writeMicroseconds(pulse); break;
      case 1: fin2Servo.writeMicroseconds(pulse); break;
      case 2: fin3Servo.writeMicroseconds(pulse); break;
      default: fin4Servo.writeMicroseconds(pulse); break;
    }
  }

  Servo fin1Servo;
  Servo fin2Servo;
  Servo fin3Servo;
  Servo fin4Servo;
};

extern Spl07 spl07;

static bool configureLsm6() {
  if (spiRead8(IMU_SENSOR_CS, 0x0f) != 0x6a) return false;
  spiWrite8(IMU_SENSOR_CS, 0x10, 0x70); // 833 Hz accelerometer, +/-2 g
  spiWrite8(IMU_SENSOR_CS, 0x11, 0x70); // 833 Hz gyro, 245 dps
  return true;
}

static bool configureLis2dh() {
  if (spiRead8(ACCEL_SENSOR_CS, 0x0f) != 0x33) return false;
  spiWrite8(ACCEL_SENSOR_CS, 0x20, 0x97); // 400 Hz, all axes
  spiWrite8(ACCEL_SENSOR_CS, 0x23, 0x08); // high-resolution, +/-2 g
  return true;
}

static bool configureA3g4250() {
  if (spiRead8(GYRO_SENSOR_CS, 0x0f) != 0xd3) return false;
  spiWrite8(GYRO_SENSOR_CS, 0x20, 0x8f); // 800 Hz, normal mode, all axes
  spiWrite8(GYRO_SENSOR_CS, 0x23, 0x00);
  return true;
}

static bool recoverSensor(SensorId sensor) {
  bool recovered = false;
  switch (sensor) {
    case SENSOR_SPL07: recovered = spl07.begin(); break;
    case SENSOR_LSM6: recovered = configureLsm6(); break;
    case SENSOR_LIS2DH: recovered = configureLis2dh(); break;
    case SENSOR_A3G4250: recovered = configureA3g4250(); break;
  }
  sensorFailures[sensor] = recovered ? 0 : sensorFailures[sensor];
  return recovered;
}

static void sensorHealthCheck(uint32_t now) {
  if (now - lastSensorHealthCheck < sensor_health_period_ms) return;
  lastSensorHealthCheck = now;
  const bool healthy[4] = {
      spiRead8(BARO_SENSOR_CS, 0x0d) == 0x10,
      spiRead8(IMU_SENSOR_CS, 0x0f) == 0x6a,
      spiRead8(ACCEL_SENSOR_CS, 0x0f) == 0x33,
      spiRead8(GYRO_SENSOR_CS, 0x0f) == 0xd3};
  for (uint8_t index = 0; index < 4; ++index) {
    if (healthy[index]) {
      sensorFailures[index] = 0;
      sensorHealthy[index] = true;
    } else if (++sensorFailures[index] >= sensor_recovery_limit) {
      sensorHealthy[index] = recoverSensor(static_cast<SensorId>(index));
    } else {
      sensorHealthy[index] = false;
    }
  }
}

Spl07 spl07(BARO_SENSOR_CS);
AltitudeKalman altitudeFilter;
FinController finController;
float rollEstimate = 0.0f;
float pitchEstimate = 0.0f;
uint32_t lastUpdateMicros;
uint32_t lastBarometerSampleMs = 0;
uint32_t lastTelemetryMs = 0;
float referencePressurePa;
float latestPressurePa = NAN;
uint8_t highAltitudeSamples = 0;
bool highAltitudeMosfetsActive = false;

static void publishRemoteTelemetry(const FlightStatePacket &packet);
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
void loop() {
  watchdog_update();
  uint32_t now = micros();
  float dt = (now - lastUpdateMicros) * 1.0e-6f;
  lastUpdateMicros = now;
  if (dt <= 0.0f || dt > 0.1f) {
    finController.disable();
    return;
  }
  uint32_t nowMillis = millis();
  sensorHealthCheck(nowMillis);

  Vector3 lisAcceleration = readLis2dh(ACCEL_SENSOR_CS);
  ImuSample lsm6 = readLsm6(IMU_SENSOR_CS);
  bool lisUsable = accelerometerIsUsable(lisAcceleration);
  bool lsmUsable = accelerometerIsUsable(lsm6.acceleration);
  Vector3 acceleration = lisUsable ? lisAcceleration : lsm6.acceleration;
  if (lisUsable && lsmUsable) {
    float accelerationDisagreement = vectorMagnitude({lisAcceleration.x - lsm6.acceleration.x,
                                                       lisAcceleration.y - lsm6.acceleration.y,
                                                       lisAcceleration.z - lsm6.acceleration.z});
    acceleration = accelerationDisagreement < 3.0f
                       ? averageVector(lisAcceleration, lsm6.acceleration)
                       : lisAcceleration;
  }
  if (!lisUsable && !lsmUsable) {
    acceleration = {0.0f, 0.0f, 9.80665f};
  }
  Vector3 externalGyro = readA3g4250(GYRO_SENSOR_CS);
  bool lsmGyroUsable = validVector(lsm6.gyro) && vectorMagnitude(lsm6.gyro) < 10.0f;
  bool externalGyroUsable = validVector(externalGyro) && vectorMagnitude(externalGyro) < 10.0f;
  Vector3 gyro = lsmGyroUsable && externalGyroUsable
                     ? averageVector(lsm6.gyro, externalGyro)
                     : (lsmGyroUsable ? lsm6.gyro : (externalGyroUsable ? externalGyro : Vector3{0.0f, 0.0f, 0.0f}));
  float measuredRoll = atan2f(acceleration.y, acceleration.z);
  float measuredPitch = atan2f(-acceleration.x, sqrtf(acceleration.y * acceleration.y + acceleration.z * acceleration.z));
  if (!isfinite(measuredRoll) || !isfinite(measuredPitch) || !isfinite(gyro.x) || !isfinite(gyro.y)) {
    finController.disable();
    return;
  }
  rollEstimate += gyro.x * dt;
  pitchEstimate += gyro.y * dt;
  rollEstimate += ATTITUDE_ACCEL_CORRECTION * (measuredRoll - rollEstimate);
  pitchEstimate += ATTITUDE_ACCEL_CORRECTION * (measuredPitch - pitchEstimate);
  if (!isfinite(rollEstimate) || !isfinite(pitchEstimate)) {
    rollEstimate = measuredRoll;
    pitchEstimate = measuredPitch;
  }
  float roll = rollEstimate;
  float pitch = pitchEstimate;
  bool motionSensorsHealthy = sensorHealthy[SENSOR_LSM6] &&
                              sensorHealthy[SENSOR_LIS2DH] &&
                              sensorHealthy[SENSOR_A3G4250];
  bool currentMotionSampleValid = lisUsable && lsmUsable &&
                                  lsmGyroUsable && externalGyroUsable;
  bool controlsArmed = FIN_CONTROL_ENABLED && motionSensorsHealthy &&
                       currentMotionSampleValid &&
                       digitalRead(MOSFET_ARM_INPUT_PIN) == HIGH;
  finController.correct(roll, pitch, controlsArmed);
  float sinRoll = sinf(roll);
  float cosRoll = cosf(roll);
  float sinPitch = sinf(pitch);
  float cosPitch = cosf(pitch);
  float verticalAcceleration = acceleration.x * sinPitch + acceleration.y * sinRoll * cosPitch + acceleration.z * cosRoll * cosPitch - 9.80665f;
  altitudeFilter.predict(verticalAcceleration, dt);
  bool pressureConfirmed = false;
  if (nowMillis - lastBarometerSampleMs >= BAROMETER_SAMPLE_PERIOD_MS) {
    lastBarometerSampleMs = nowMillis;
    float pressure = spl07.pressurePa();
    latestPressurePa = pressure;
    bool pressureUsable = isfinite(pressure) && pressure > 30000.0f && pressure < 120000.0f;
    if (pressureUsable) {
      float pressureAltitude = 44330.0f * (1.0f - powf(pressure / referencePressurePa, 0.19029495f));
      if (isfinite(pressureAltitude) && fabsf(pressureAltitude - altitudeFilter.altitude()) < 150.0f) {
        altitudeFilter.correct(pressureAltitude);
        pressureConfirmed = true;
      }
    }
  }
  updateHighAltitudeOutputs(altitudeFilter.altitude(), pressureConfirmed);
  sendFlightState(nowMillis, latestPressurePa);
  if (nowMillis - lastTelemetryMs >= TELEMETRY_PERIOD_MS) {
    lastTelemetryMs = nowMillis;
    Serial.print(altitudeFilter.altitude(), 3);
    Serial.print(',');
    Serial.println(altitudeFilter.velocity(), 3);
  }
}
static void publishRemoteTelemetry(const FlightStatePacket &packet) {
  char record[160];
  int recordLength = snprintf(record, sizeof(record), "%lu,%.3f,%.3f,%.5f,%.5f,%.2f,%02X",
                              static_cast<unsigned long>(packet.timestampMs), packet.altitudeM,
                              packet.velocityMps, packet.rollRad, packet.pitchRad,
                              packet.pressurePa, packet.sensorHealthMask);
  if (recordLength <= 0 || recordLength >= static_cast<int>(sizeof(record))) return;
  if (sdCardReady) {
    flightLog.println(record);
    if (packet.timestampMs - lastSdFlushMs >= SD_FLUSH_PERIOD_MS) {
      flightLog.flush();
      lastSdFlushMs = packet.timestampMs;
    }
  }
  static uint32_t lastRadioTransmissionMs = 0;
  if (loraReady && packet.timestampMs - lastRadioTransmissionMs >= TELEMETRY_PERIOD_MS) {
    loraRadio.transmit(record);
    lastRadioTransmissionMs = packet.timestampMs;
  }
}

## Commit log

2026-08-24 Coed :P (I added kalman filters and other things to make the chip work)
2026-08-25 kalman filter upgrades
2026-08-28 Added a Bill Of Materials (BOM) file to the project to make stardance funding easier.
    [BOM.csv]
2026-09-08 Fixed BOM, Also added PCB Files
    [BOM.csv]
2026-09-08 Added PCB Dependancies
    [Avionics Board.kicad_pcb, Avionics Board.kicad_sch]
2026-10-03 Finalized File Structure and added all PCB Files
    [Avionics Board-B_Cu.gbr, Avionics Board-B_Mask.gbr, Avionics Board-B_Paste.gbr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]
2026-10-03 Organized Files and cleaned up workspace
    [Avionics Board.kicad_pcb, Avionics Board.kicad_sch]
2026-10-06 Update README with component details and software info
    Added details about specific components used in the project, including the accelerometer, barometer, gyroscope, and inertial measurement unit. Also included information about the software used and th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
2026-10-14 Update README with schematics section
    Added section about schematics to README.
2026-10-15 Revise README for filter and wiring/schematic details
    Updated sections on the filter and schematics/wiring in the README.
2026-10-15 Enhance README with wiring and schematic details
    Added descriptions for the wiring/silkscreen and schematic sections.
2026-10-15 Enhance README with board design and personal touches
    Added personal touches and images to showcase board design.
2026-10-29 Fix typo in BOM.csv for cost description
2026-10-29 Adjust PCB and total costs in BOM
    Updated PCB and total costs in BOM.csv.
